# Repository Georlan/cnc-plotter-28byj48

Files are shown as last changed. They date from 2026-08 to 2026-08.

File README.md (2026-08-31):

# CNC Plotter 28BYJ-48 — baixo custo, impressa em 3D

Plotter cartesiana para papel A5, modelada parametricamente em OpenSCAD e
otimizada para fabricação na Bambu Lab A1.

Comece pelo [`GUIA_VISUAL_MONTAGEM.md`](GUIA_VISUAL_MONTAGEM.md). Para os
critérios detalhados dos cupons, lista de fixadores e diagnóstico, consulte
[`GUIA_TESTES_E_MONTAGEM.md`](GUIA_TESTES_E_MONTAGEM.md).

## Arquitetura atual

- Um único eixo X apoiado em **dois trilhos paralelos**.
- Trilho X dianteiro motriz: uma cremalheira, um pinhão e um 28BYJ-48.
- Trilho X traseiro passivo: sem cremalheira e sem segundo motor.
- Sapata PETG flutuante no apoio traseiro: `±0,60 mm` em Y para não travar por
  pequeno erro de paralelismo.
- Viga Y tubular de `30 x 24 mm`, parede de `1,8 mm`, diafragmas a cada
  `40 mm` e apoio nas duas extremidades.
- Papel parado; apenas pórtico, carrinho Y e caneta se movem.
- Z com mola metálica: o plástico guia a caneta, mas não define sozinho a
  pressão no papel.

O curso conservador é **148 x 180 mm** dentro de uma folha A5. A máquina segura
a folha inteira, mas mantém margem de 15 mm nas extremidades longas.

## Arquivos imprimíveis

| Arquivo | Conteúdo | Material |
|---|---|---|
| `01_Base_Trilho_X.scad` | trilho dianteiro com cremalheira | PLA |
| `01B_Trilho_X_Passivo.scad` | trilho traseiro sem cremalheira | PLA |
| `02_Carrinho_X.scad` | carrinho motriz + sela traseira | PLA |
| `02B_Sapata_X_Passiva_PETG.scad` | sapata flutuante | PETG |
| `03_Trilho_Y.scad` | viga-caixão Y com guia e rack | PLA |
| `04_Carrinho_Y.scad` | carrinho Y e suportes dos motores Y/Z | PLA |
| `05_Modulo_Z_Caneta.scad` | êmbolo Z + colar + mandril e buchas | PETG recomendado |
| `06_Pinhoes.scad` | três pinhões D de 10 dentes | PETG recomendado |
| `07_Batentes.scad` | quatro batentes X + dois Y, por pressão | PETG |
| `08_Clips_Fixacao_Papel.scad` | quatro clips de papel | PLA ou PETG |
| `91_Teste_Engrenamento_FDM.scad` | cupom rack + pinhão | material dos pinhões |
| `99B_Teste_Portaferramenta_FDM.scad` | cupom do mandril e buchas | PETG recomendado |
| `99D_Teste_Fixacao_Motor_28BYJ48.scad` | cupom da flange/ressalto do motor | PLA |

`02_Carrinho_X.scad` e `02B_Sapata_X_Passiva_PETG.scad` foram separados para
não exigir PLA e PETG na mesma placa.

### 3MF para abrir no Bambu Studio

Para imprimir pela Bambu Lab A1, prefira os arquivos da pasta
[`bambu_project_3mf/`](bambu_project_3mf/). Eles são exportados novamente pelo
**Bambu Studio oficial** e incluem a estrutura de projeto do Bambu, em vez de
serem apenas contêineres de malha 3MF produzidos pelo OpenSCAD.

O gerador está fixado em:

- Bambu Studio `2.8.2.61`;
- impressora `Bambu Lab A1 0.4 nozzle`;
- processo-base `0.16mm Optimal @BBL A1`;
- `Generic PLA @BBL A1` para `01`, `01B`, `02`, `03`, `04` e `08`;
- `Generic PETG @BBL A1` para `02B`, `05`, `06` e `07`.

Cada projeto é verificado como ZIP/3MF, precisa conter
`Metadata/project_settings.config` e `Metadata/model_settings.config`, e é
reaberto pelo Bambu Studio CLI antes de ser publicado pelo CI.

A pasta [`bambulab_3mf/`](bambulab_3mf/) continua existindo como saída
**geométrica** do OpenSCAD. Ela é útil para intercâmbio e inspeção, mas o Bambu
Studio pode tratá-la como 3MF genérico/importado e pedir confirmação de
configuração. Para o fluxo normal de impressão, use `bambu_project_3mf/`.

Os projetos Bambu usam um perfil-base válido; os ajustes mecânicos específicos
de brim, paredes e preenchimento continuam descritos na seção **Fatiamento
econômico na Bambu Lab A1** abaixo. Antes de enviar à impressora, confira na
placa o material selecionado e mantenha suporte desativado nas regiões de guia.

Para regenerar os dois conjuntos:

```bash
./build_3mf.sh
./build_bambu_project_3mf.sh
```

## Parâmetros principais

- Trilhos X: `220 x 26 mm`; distância entre centros: `240 mm`.
- Viga Y: `240 x 30 x 24 mm`.
- Guia XY: rabo de andorinha, folga inicial `0,22 mm` por lado.
- Guia Z: folga inicial `0,15 mm` por lado e 22 mm de comprimento guiado.
- Cremalheira: passo circular `4,0 mm`.
- Pinhão: 10 dentes, perfil involuta *stub*, ângulo de pressão de 30°.
- A raiz dos dentes tem `0,20 mm` de sobreposição no cubo para manter a peça
  manifold e evitar o falso efeito de transparência no preview OpenCSG.
- O módulo do pinhão força `render(convexity=10)`, necessário para o preview F5
  do OpenSCAD 2021 mostrar dentes sólidos em vez das faces vazadas do OpenCSG.
- Relação cinemática correta: **9° de pinhão por mm linear**; 4 mm correspondem
  a 36°, não a uma volta completa.

Antes das peças longas, imprima `99_Teste_Tolerancias.scad`,
`91_Teste_Engrenamento_FDM.scad` e `99D_Teste_Fixacao_Motor_28BYJ48.scad`.
Use a menor folga que deslize sem força após retirar rebarbas e valide o motor
real no cupom antes de gastar material com os carrinhos completos.

## Interface dos motores 28BYJ-48

A montagem dos três motores usa o **centro do eixo como datum**. O ressalto
frontal nominal de 9 mm entra num alojamento coaxial e localiza o motor em
relação ao pinhão. Os parafusos das orelhas servem apenas para prender o motor.

O desenho dimensional nominal do 28BYJ-48 possui `35 mm` entre os furos e uma
linha de furos deslocada aproximadamente `8 mm` em relação ao centro do eixo.
Como há variantes comerciais, os suportes usam dois rasgos M3 com `±2 mm` de
ajuste por orelha, cobrindo aproximadamente `31–39 mm` entre centros sem mover
o eixo. O modelo visual, os carrinhos X/Y/Z e os parafusos da montagem completa
usam a mesma interface canônica definida em `00_Parametros.scad`.

O motor Z é girado 180° ao redor do próprio eixo para que suas orelhas fiquem
abaixo do eixo e ancoradas na torre do carrinho Y. Isso não altera a posição do
pinhão nem a relação rack/pinhão.

## Porta-ferramenta universal

O guia Z continua usando uma haste rígida de `10 mm`, mas a ferramenta agora
fica num mandril externo de `24 mm` de altura. Isso permite trocar caneta por
pincel sem enfraquecer o êmbolo, alterar a mola ou reposicionar o motor Z.

- buchas incluídas para cabos redondos nominais de `7,5`, `10,0` e `12,5 mm`;
- cabos de aproximadamente `14–15 mm` podem ser presos sem bucha;
- use a menor bucha na qual o cabo entre sem força e aperte o M3 só até eliminar
  o giro; não comprima a madeira nem a virola metálica do pincel;
- prenda o cabo redondo acima da virola. Pincéis com cabo cônico devem ser
  posicionados numa região quase cilíndrica.

Imprima primeiro `99B_Teste_Portaferramenta_FDM.scad`: ele contém o mesmo
mandril da peça final, mas sem a longa haste, e evita gastar material caso seja
necessário recalibrar a folga para sua impressora.

## Altura e pressão da ferramenta

- Curso total do motor Z: `8 mm`.
- Compressão nominal no contato: `2 mm`.
- Elevação livre real: `6 mm`.
- Ponta baixa: `Z = 0,30 mm`, na superfície modelada do papel.
- Ponta alta: `Z = 6,30 mm`.
- Mola-alvo: `0,20 N/mm`, pré-carga de `1 mm`, curso complacente de `3 mm`.
- Força nominal modelada: aproximadamente `0,60 N`.
- Força no fim do curso complacente: aproximadamente `0,80 N`.

Uma mola entre `0,15 e 0,25 N/mm` é aceitável. Ajuste primeiro a altura do
colar com a máquina desligada; não use o motor para esmagar a ponta na mesa.

## Massa e rigidez

Volumes medidos nos STLs renderizados:

- peças móveis impressas: aproximadamente **154 g**;
- três motores, usando 35 g por motor como referência: aproximadamente 105 g;
- caneta, mola e fixadores móveis: aproximadamente 15–25 g;
- conjunto móvel estimado: **274–284 g**.

O valor dos motores varia por fabricante. A estimativa não substitui a pesagem.

Para a viga 30 x 24 x 1,8 mm, um cálculo simplificado de viga biapoiada com
1,3 N no centro e módulo de PLA de 1,8 GPa resulta em cerca de `0,013 mm` de
deflexão elástica. Isso não é FEA: juntas, empenamento e montagem fora de
esquadro dominarão o erro real.

## Fatiamento econômico na Bambu Lab A1

### Trilhos e viga em PLA

- camada: `0,24 mm`;
- gerador de paredes: Arachne;
- 3 paredes;
- 4 camadas de topo/fundo;
- 10% Gyroid nos blocos locais;
- brim de 5–8 mm nos trilhos de 220 mm e 5 mm na viga de 240 mm;
- suporte desativado.

### Carrinhos em PLA

- camada: `0,20 ou 0,24 mm`;
- 4 paredes;
- 15% Gyroid;
- suporte desativado.

### Sapata, Z e pinhões em PETG

- camada: `0,20 mm`;
- 4 paredes;
- pinhões: 100% de preenchimento;
- sapata/Z: 20–30%;
- seque o PETG antes de imprimir as superfícies de guia.

Os canais inferiores têm 0,25 mm de profundidade e pontes de no máximo 10 mm.
Não ative suporte dentro deles.

## Parafusos mínimos

- 8x M4 para os dois trilhos (quatro por trilho);
- 6x M3 para os três motores (dois por motor);
- 2x M3 para as extremidades da viga;
- 1x M3x8 para reter a sapata sem apertar a sela;
- 1x M3 para o colar da haste;
- 1x M3 com porca para o mandril da caneta ou do pincel.

Total estrutural: **19 parafusos**. Batentes são de pressão e os clips de papel
podem usar fita dupla-face.

## Montagem sem perder o esquadro

1. Fixe totalmente apenas o trilho dianteiro.
2. Deixe os quatro parafusos do trilho traseiro levemente soltos.
3. Monte os dois carrinhos e a viga, sem forçar a sapata passiva.
4. Desloque o pórtico manualmente por todo o X.
5. Aperte o trilho traseiro aos poucos, alternando posições do pórtico.
6. Aperte o M3 da sapata contra o ressalto; a sela deve continuar movendo
   aproximadamente `±0,60 mm`.
7. Só então monte motores e ajuste o engrenamento.

## Validação

Com o OpenSCAD CLI instalado:

```bash
python3 validate_geometry.py
```

Testes:

- `91_Teste_Engrenamento_FDM.scad`: cupom físico barato do perfil real;
- `92_Teste_Estrutural.scad`: dimensões, esbeltez e área A5;
- `93_Teste_Plano_Caneta.scad`: altura, elevação, força e guia Z;
- `94_Teste_Engrenamento_Dinamico.scad`: 17 amostras em um passo completo;
- `95_Teste_Montagem_Completa.scad`: interfaces e colisões estruturais;
- `96_Validacao_Curso.scad`: centro e quatro extremos para inspeção visual;
- `97_Diagnostico_Motores.scad`: corpo, flange, ressalto e eixo dos motores;
- `98_Teste_Interferencias.scad`: bolsos de pinhão e curso Z;
- `99_Teste_Tolerancias.scad`: cupom físico de folgas;
- `99_Teste_Folga_Pinhao_FDM.scad`: folgas radial e axial do bolso;
- `99B_Teste_Portaferramenta_FDM.scad`: mandril e três buchas redutoras;
- `99D_Teste_Fixacao_Motor_28BYJ48.scad`: ressalto, eixo e rasgos das orelhas.

Os testes 92–95 e 97–98 devem exportar somente seu cubo marcador de 1 mm.
Geometria adicional indica colisão.

Para gerar somente os STLs imprimíveis:

```bash
./build_stl.sh
```

## Limite elétrico

Não alimente um 28BYJ-48 de 5 V diretamente com 12 V. Esta revisão mecânica não
depende dessa modificação. Use aceleração moderada no firmware e valide perda
de passos com quadrados e círculos antes do trabalho final.

## Licença

Hardware aberto para uso pessoal e educacional.

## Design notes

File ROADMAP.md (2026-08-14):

# Roadmap — CNC Plotter 28BYJ-48

Este roadmap acompanha o estado real do projeto. As medidas continuam em
`00_Parametros.scad`; resultados físicos podem alterar folgas sem invalidar a
sequência abaixo.

## Estado atual

- [x] Estrutura paramétrica completa em OpenSCAD.
- [x] Trilhos X duplos, viga Y apoiada e módulo Z redesenhados.
- [x] Motores e pinhões posicionados nos três eixos.
- [x] Folgas de segurança e porta-ferramenta para caneta/pincel adicionados.
- [x] Testes de impressão e guias de montagem preparados.
- [x] Simulação 3D interativa em `GUIA_3D_INTERATIVO.html`.
- [ ] Validar as tolerâncias na impressora real.

## Fase 1 — Cupons antes das peças grandes

- [ ] Imprimir `91_Teste_Engrenamento_FDM.scad` e escolher o engrenamento que
  gira continuamente, sem salto e sem forçar o eixo.
- [ ] Imprimir `99_Teste_Folga_Pinhao_FDM.scad` e registrar a melhor folga.
- [ ] Imprimir `99_Teste_Tolerancias.scad` e registrar as folgas que deslizam
  sem jogo excessivo.
- [ ] Imprimir `99B_Teste_Portaferramenta_FDM.scad` com o material final e
  testar caneta e pincel.
- [ ] Atualizar somente os parâmetros correspondentes em `00_Parametros.scad`.

**Portão de avanço:** todos os cupons devem passar antes de imprimir trilhos,
viga e carrinhos completos.

## Fase 2 — Impressão e inspeção

- [ ] Gerar os STL com `build_stl.sh` após calibrar os cupons.
- [ ] Imprimir pinhões e peças de precisão primeiro; depois as peças longas.
- [ ] Remover rebarbas sem desgastar dentes ou superfícies de referência.
- [ ] Conferir empenamento, furos, encaixes, rachaduras e camadas.
- [ ] Separar parafusos, porcas, mola, motores, drivers e fonte.

## Fase 3 — Montagem mecânica sem energia

- [ ] Fixar o trilho X motriz e deixar o trilho X passivo levemente solto.
- [ ] Inserir os dois carrinhos X e montar sapata/sela passiva.
- [ ] Assentar a viga Y nas chavetas e usá-la para alinhar os trilhos X.
- [ ] Percorrer todo o curso X e apertar o trilho passivo gradualmente.
- [ ] Inserir o carrinho Y antes dos batentes.
- [ ] Montar êmbolo, mola, colar e porta-ferramenta do eixo Z.
- [ ] Instalar motores e aproximar os pinhões sem pré-carga radial.

**Portão de avanço:** X, Y e Z devem mover manualmente em todo o curso, sem
pontos duros, colisões, salto de dentes ou flexão visível dos eixos.

## Fase 4 — Elétrica e segurança

- [ ] Alimentar os três ULN2003 com fonte externa regulada de 5 V e margem de
  corrente; não alimentar todos os motores pelo pino 5 V do Arduino.
- [ ] Unir o GND da fonte ao GND do Arduino.
- [ ] Ligar um motor por vez e conferir temperatura, ruído e giro.
- [ ] Organizar cabos com folga para todo o curso e longe das engrenagens.
- [ ] Manter um desligamento rápido disponível nos primeiros testes.

| Eixo | ULN2003 no Arduino Uno |
|---|---|
| X | IN1–IN4 em D2–D5 |
| Y | IN1–IN4 em D6–D9 |
| Z | IN1–IN4 em D10–D13 |

## Fase 5 — Firmware e calibração

- [x] Firmware `CNC_Plotter_28BYJ48.ino` criado para três 28BYJ-48.
- [ ] Gravar o firmware e validar a serial em 115200 baud.
- [ ] Testar um eixo por vez em baixa velocidade.
- [ ] Mandar 10 mm, medir e recalcular `STEPS_PER_MM`; repetir com 50 mm.
- [ ] Ajustar velocidade e aceleração até eliminar perda de passos.
- [ ] Confirmar que Z não esmaga o pincel contra o papel.

## Fase 6 — Movimento e desenho

- [ ] Rodar o teste de interferências nos extremos do curso.
- [ ] Desenhar linhas, quadrado e diagonais; medir esquadro e repetibilidade.
- [ ] Executar `G-code-to-write-a-spiral.ngc` para movimento contínuo X/Y.
- [ ] Executar `G-code-to-write-ABC+Hatched.ngc` para validar X/Y/Z.
- [ ] Repetir o desenho três vezes e comparar retorno, pressão e passos perdidos.
- [ ] Registrar material, camada, folgas, passos/mm, velocidade e resultado.

## Fase 7 — Melhorias após a primeira máquina funcional

- [ ] Fins de curso e homing automático.
- [ ] Fixação definitiva do papel e superfície substituível.
- [ ] Alívio de tração e guia para cabos.
- [ ] Avaliar motores mais fortes somente se os testes comprovarem falta de
  torque; primeiro eliminar atrito, desalinhamento e pré-carga.

## Documentos de apoio

- `GUIA_3D_INTERATIVO.html` — montagem e movimento em 3D.
- `GUIA_VISUAL_MONTAGEM.md` — referência visual rápida.
- `GUIA_TESTES_E_MONTAGEM.md` — critérios e lista de fixadores.
- `CNC_Plotter_Animated_Simulation.scad` — simulação paramétrica no OpenSCAD.

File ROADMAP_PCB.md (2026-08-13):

# ⚡ ROADMAP AVANÇADO: Fabricação de Placas de Circuito Impresso (PCB) via Plotter CNC + Percloreto

Este roadmap foi otimizado para transformar a sua Mini CNC Plotter em uma estação dedicada à fabricação de **Placas de Circuito Impresso (PCB)** de alta precisão.

---

## 🚀 FASE 1: Hardware & Estabilidade Elétrica (Urgente)
- [ ] **Alimentação Externa 5V (2A)**:
  - Não alimentar os 3 drivers ULN2003 pela USB do Arduino.
  - Conectar fonte de 5V 2A na protoboard + GND comum no Arduino.
- [ ] **Ajuste Mecânico de Precisão (Eliminar Folgas / Backlash)**:
  - A corrosão em percloreto exige precisão de $0.1\text{ mm}$.
  - Verificar se a engrenagem do pinhão está bem presa no eixo do motor 28BYJ-48 sem patinar.
  - Adicionar molas ou pressão suave no eixo Z para a caneta não variar a força no cobre.

---

## 🖥️ FASE 2: Frontend Web Customizada (`CNC PCB Commander`)
- [x] **Substituição do UGS por Interface Nativa Otimizada**:
  - Criado servidor local `cnc_web_server.py` e frontend moderna em `http://localhost:8080`.
- [x] **Recursos Específicos para PCB na Web App**:
  - Visualizador 2D em tempo real das trilhas de cobre (G0 em vermelho, G1 em verde néon).
  - Controle de Jogging com precisão de $0.1\text{ mm}$, $1.0\text{ mm}$ e $5.0\text{ mm}$.
  - Botão rápido de teste de profundidade da caneta (`Z5` subir / `Z-1` baixar).
  - Transmissor G-code integrado via WebSockets (sem necessidade de Java ou UGS).

---

## 🎨 FASE 3: Fluxo de G-Code de PCB (Gerber / SVG $\rightarrow$ G-Code)
- [ ] **Desenho da Placa no CAD (KiCad / EasyEDA)**:
  - Desenhar as trilhas com largura mínima de $0.5\text{ mm}$ ($20\text{ mil}$) e pads aumentados para facilitar a furação.
  - Exportar o layer de trilhas (*Bottom Copper*) em SVG ou Gerber.
- [ ] **Compensação de Espessura da Caneta (Inkscape)**:
  - Importar o SVG no Inkscape.
  - Converter trilhas em contornos com traço de $0.4\text{ mm}$ (diâmetro exato da ponta da caneta permanente).
  - Gerar o G-code utilizando o plugin *Inkscape Gcodetools*.

---

## 🧪 FASE 4: Processo de Desenho e Corrosão em Percloreto de Ferro ($\text{FeCl}_3$)
- [ ] **1. Preparação da Placa de Fenolite / Cobre**:
  - Lixar suavemente a placa de cobre com palha de aço bem fina (Bombril) até o cobre ficar brilhante e 100% sem oxidação.
  - Limpar com álcool isopropílico para remover qualquer oleosidade de dedos (a gordura impede a aderência da tinta e do ácido).
- [ ] **2. Caneta Recomendada**:
  - Utilizar canetas permanentes à base de solvente e resistentes a ácido:
    - *Staedtler Lumocolor Permanent (Ponta S 0.4mm ou F 0.6mm)*
    - *Pilot CD/DVD Marker*
- [ ] **3. Desenho Automático com Passe Duplo**:
  - Fixar a placa na mesa da CNC com fita dupla face para não mover.
  - Zerar a caneta no canto inferior esquerdo da placa (`X0, Y0, Z0`).
  - Executar o desenho via **CNC PCB Commander** (`http://localhost:8080`).
  - Habilitar o **Passe Duplo de Tinta** no painel da Web App para garantir camada espessa que impede o percloreto de corroer microfuros na tinta.
- [ ] **4. Banho de Percloreto de Ferro**:
  - Diluir o percloreto em recipiente plástico (nunca metálico!).
  - Dica de Ouro: Aqueça a água da solução até $\sim 40^\circ\text{C}$ e agite suavemente a placa durante a corrosão. O processo levará apenas de 8 a 12 minutos.
- [ ] **5. Limpeza e Furação**:
  - Remover a tinta preta com álcool ou acetona.
  - Furar os ilhós dos componentes com mini furadeira / retífica e broca de $0.8\text{ mm}$ a $1.0\text{ mm}$.

---

## 🎯 FASE 5: Automações Futuras na CNC
- [ ] Implementação de Auto-Leveling (Mapeamento de desnível da placa de cobre via pino sensor no Arduino).
- [ ] Adaptação de spindle / micro-retífica para furação automática de PCBs.

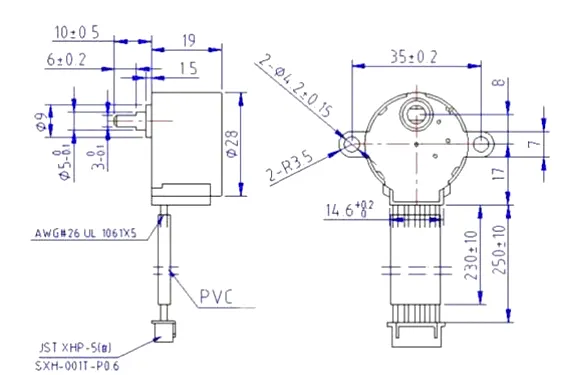
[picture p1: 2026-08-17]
28BYJ-48-dimensions.webp

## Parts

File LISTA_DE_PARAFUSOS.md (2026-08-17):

# 🔩 Lista de Parafusos e Fixadores — CNC Plotter 28BYJ-48

Esta é a lista completa de todos os parafusos, porcas e elementos de fixação necessários para a montagem completa da CNC.

---

## 📋 1. Tabela Detalhada de Aplicação

| Item | Qtd | Especificação | Onde é usado | Instrução de Aperto |
|:---:|:---:|:---|:---|:---|
| **1** | **8x** | **M4** *(12mm a 20mm, dependendo da base)* | Fixação dos dois Trilhos X na base de MDF | Firme, sem deformar o piso plástico do trilho |
| **2** | **6x** | **M3 x 8mm** + **6x Porcas M3** | Fixação dos 3 motores 28BYJ-48 (2 por motor: X, Y, Z) | Aperto suave nas orelhas metálicas do motor |
| **3** | **2x** | **M3 x 10mm** | Fixação das 2 pontas da Viga Y nos carrinhos X | Rosca direta no piloto plástico; sem espanar |
| **4** | **1x** | **M3 x 8mm** | Parafuso limitador da sela/sapata passiva traseira | Encostar no ressalto sem travar a flutuação lateral |
| **5** | **1x** | **M3 x 12mm** + **1x Porca M3** | Aperto do colar limitador da haste Z | Firme para não escorregar durante o desenho |
| **6** | **1x** | **M3 x 14mm** (ou 16mm) + **1x Porca M3** | Aperto do mandril universal (caneta/pincel) | Apertar até travar o giro, sem esmagar o cabo |

---

## 📦 2. Resumo Consolidado para Compra

### Parafusos (Total: 19 unidades)
- [ ] **8x** Parafusos **M4** (Comprimento conforme sua base: 12mm a 20mm)
- [ ] **7x** Parafusos **M3 x 8mm** (Cabeça Cilíndrica Allen ou Philips)
- [ ] **2x** Parafusos **M3 x 10mm**
- [ ] **1x** Parafuso **M3 x 12mm**
- [ ] **1x** Parafuso **M3 x 14mm** (ou 16mm)

### Porcas e Arruelas
- [ ] **8x** Porcas sextavadas **M3**
- [ ] **8x** Arruelas lisas **M4** *(Recomendado para não marcar o plástico da base X)*
- [ ] **6x** Arruelas lisas **M3** *(Recomendado para as abas dos motores)*

### Molas e Complementos
- [ ] **1x** **Mola de compressão metálica** *(Diâmetro externo: 6 a 8 mm, Comprimento livre: 15 a 25 mm, Rigidez leve/média — pode usar mola de caneta retrátil)*
- [ ] **4x** Fixadores opcionais para os clips de papel *(ou fita dupla face)*

---

## 💡 Dicas de Montagem:
1. **Nunca aperte excessivamente no plástico:** Os furos pilotos impressos em 3D aceitam rosca do próprio parafuso M3, mas apertar com força excessiva pode espanar a rosca interna.
2. **Alojamentos de Porcas Hexagonais:** No mandril da caneta e nos suportes dos motores, os encaixes das porcas M3 foram desenhados para encaixe sob leve pressão. Se a porca entrar justa, puxe-a para o lugar rosqueando o parafuso pelo lado oposto.

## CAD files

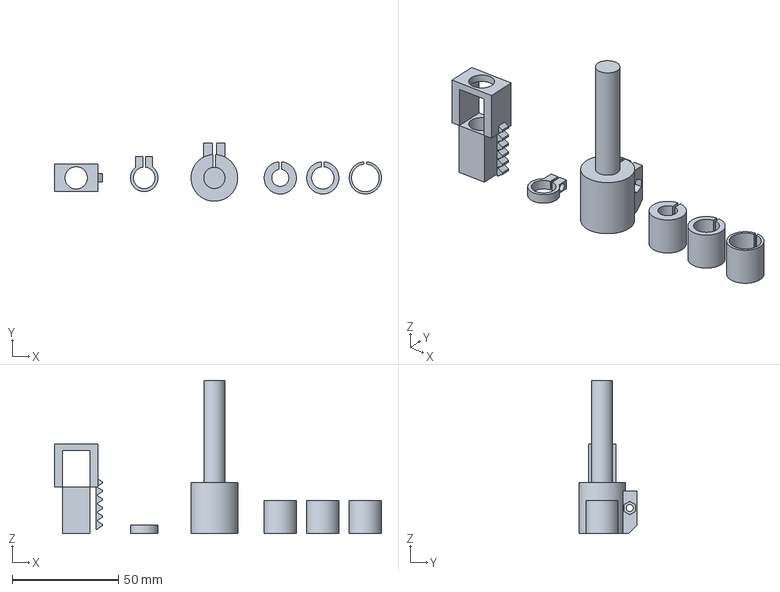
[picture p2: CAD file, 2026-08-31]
bambu_project_3mf/05_Modulo_Z_Caneta.3mf
153.8 x 27.5 x 72.0 mm

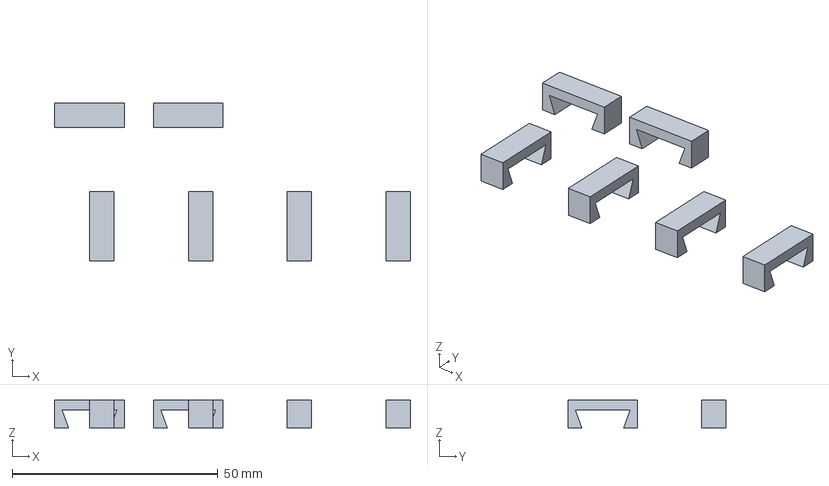
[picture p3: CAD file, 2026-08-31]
bambulab_3mf/07_Batentes.3mf
86.5 x 38.5 x 6.70 mm

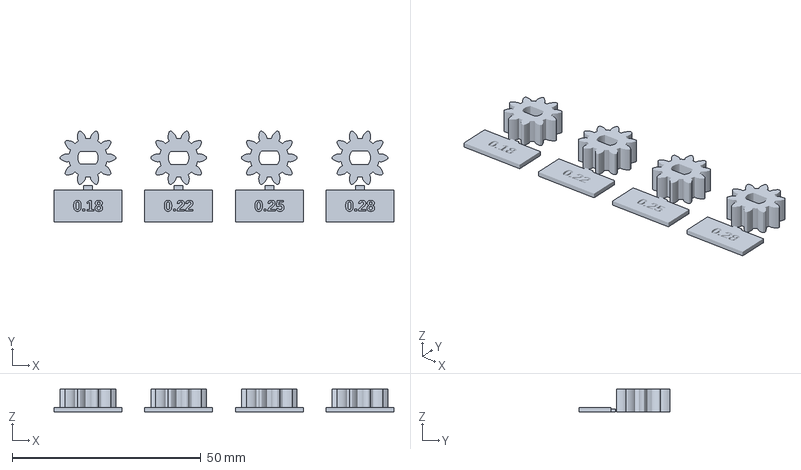
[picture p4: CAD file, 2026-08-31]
bambulab_3mf/testes/99_Teste_Eixo_D.3mf
90.0 x 24.1 x 6.00 mm

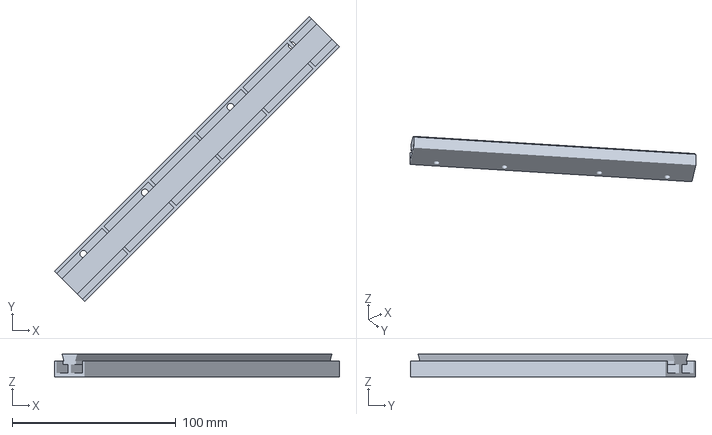
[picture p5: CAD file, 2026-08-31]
bambu_project_3mf/01B_Trilho_X_Passivo.3mf
173.9 x 173.9 x 14.0 mm

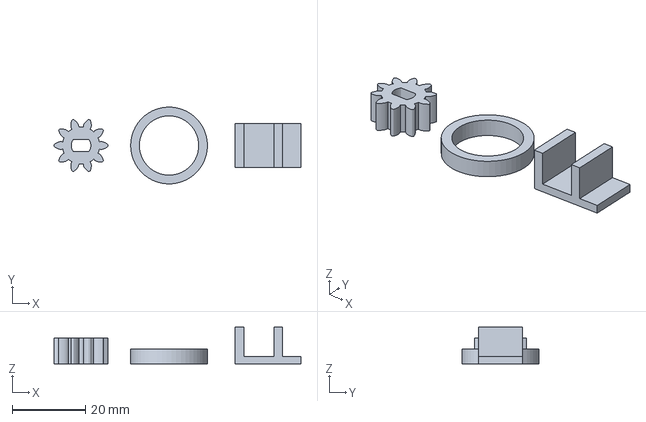
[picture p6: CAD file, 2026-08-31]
bambulab_3mf/testes/99_Teste_Folga_Pinhao_FDM.3mf
67.4 x 20.9 x 10.0 mm

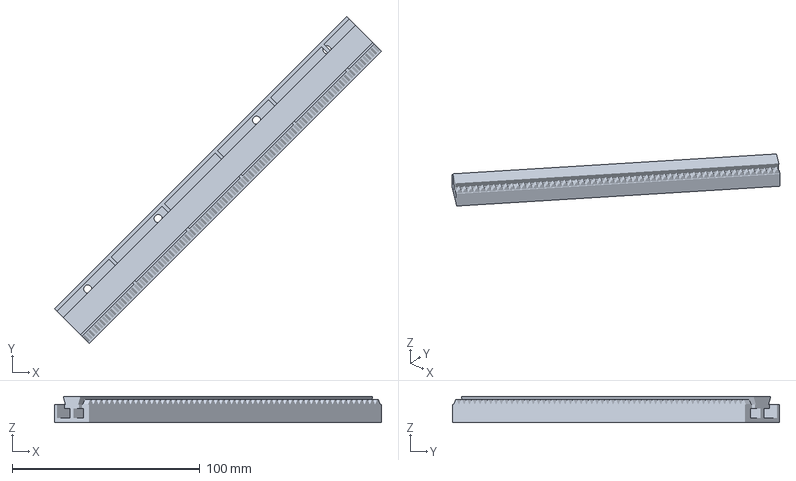
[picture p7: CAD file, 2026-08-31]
bambu_project_3mf/01_Base_Trilho_X.3mf
173.9 x 173.9 x 14.0 mm

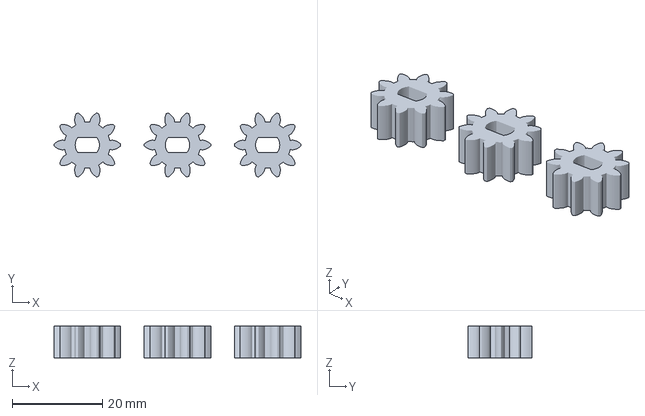
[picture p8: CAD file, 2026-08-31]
bambulab_3mf/06_Pinhoes.3mf
54.8 x 14.2 x 7.00 mm

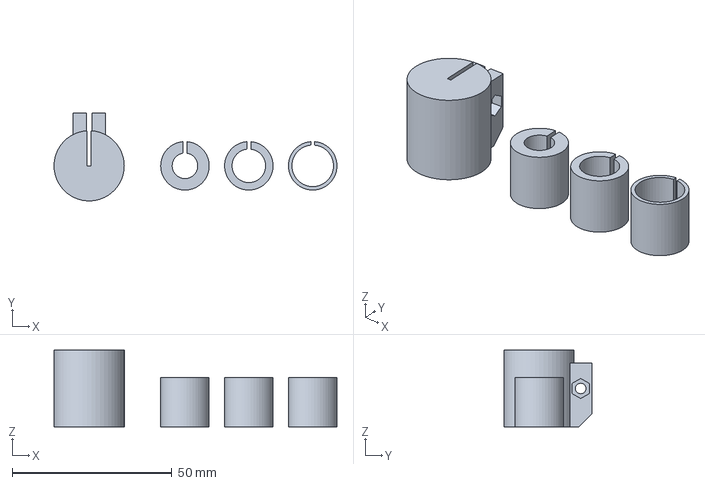
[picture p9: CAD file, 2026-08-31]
bambulab_3mf/testes/99B_Teste_Portaferramenta_FDM.3mf
88.6 x 27.5 x 24.0 mm

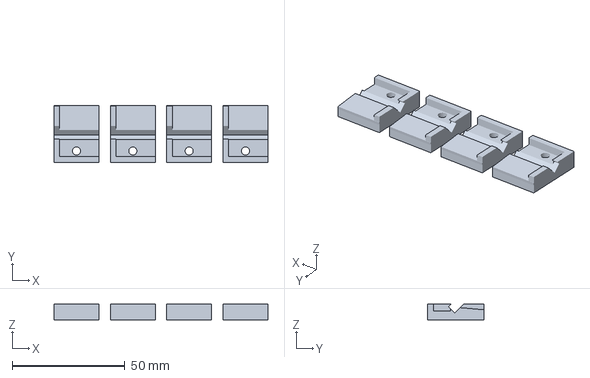
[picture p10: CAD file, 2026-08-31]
bambulab_3mf/08_Clips_Fixacao_Papel.3mf
95.0 x 25.1 x 7.00 mm

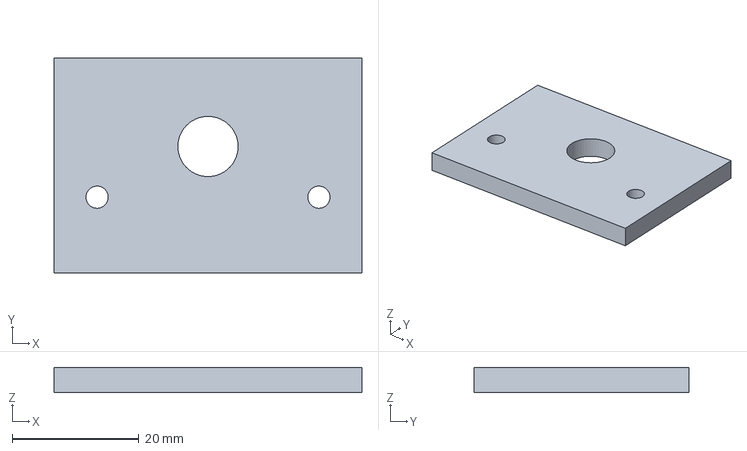
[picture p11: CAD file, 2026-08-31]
bambulab_3mf/testes/99D_Teste_Fixacao_Motor_28BYJ48.3mf
48.6 x 34.0 x 4.00 mm

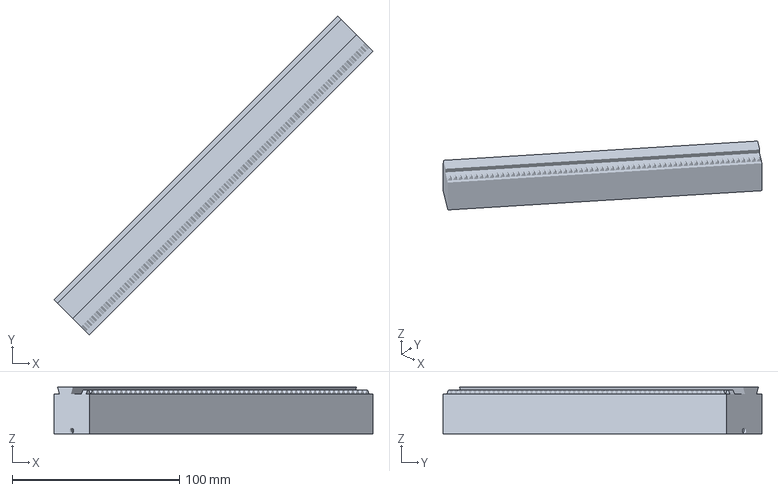
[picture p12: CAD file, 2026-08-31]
bambu_project_3mf/03_Trilho_Y.3mf
190.9 x 190.9 x 28.0 mm

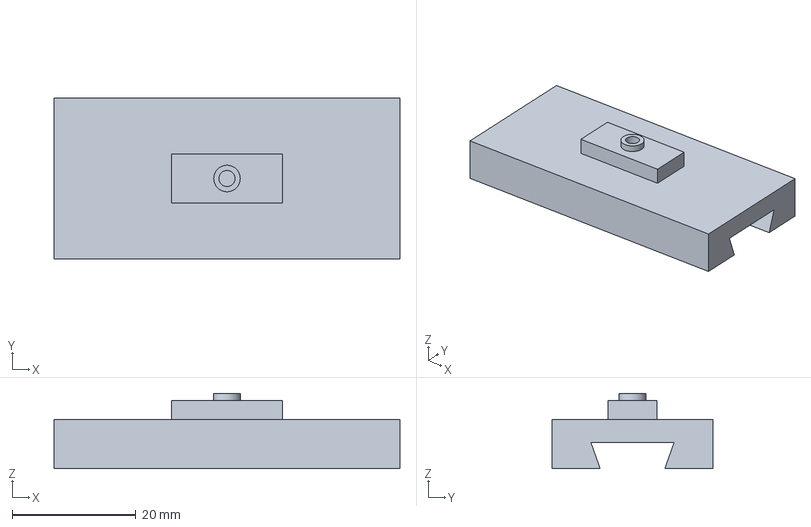
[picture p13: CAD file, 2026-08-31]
bambulab_3mf/02B_Sapata_X_Passiva_PETG.3mf
56.0 x 26.0 x 12.2 mm

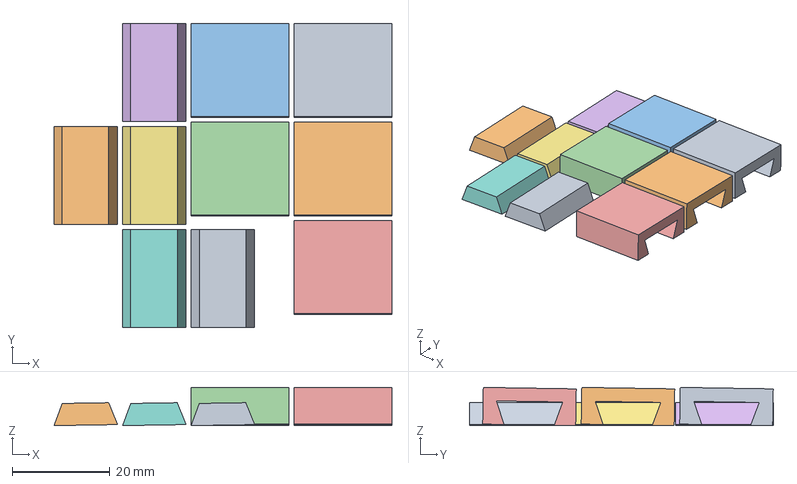
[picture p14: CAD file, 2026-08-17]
bambulab_3mf/testes/99_Teste_Tolerancias.3mf
69.0 x 62.0 x 7.80 mm
99_Teste_Tolerancias.stl_1
99_Teste_Tolerancias.stl_2
99_Teste_Tolerancias.stl_3
99_Teste_Tolerancias.stl_4
99_Teste_Tolerancias.stl_5
99_Teste_Tolerancias.stl_6
99_Teste_Tolerancias.stl_7
99_Teste_Tolerancias.stl_8
99_Teste_Tolerancias.stl_9
99_Teste_Tolerancias.stl_10

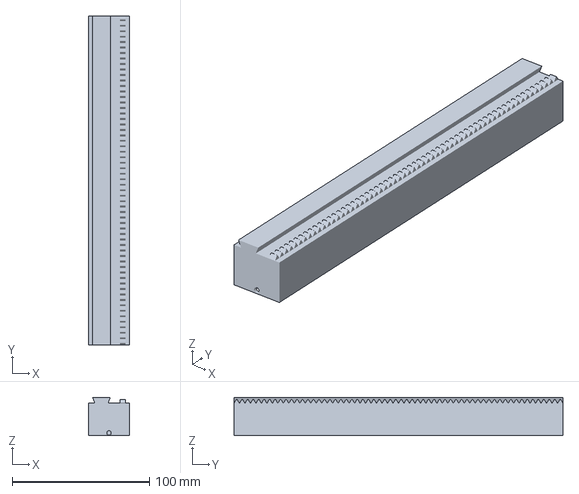
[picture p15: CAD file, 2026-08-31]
bambulab_3mf/03_Trilho_Y.3mf
30.0 x 240.0 x 28.0 mm

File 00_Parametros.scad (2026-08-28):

/*
  Parametros globais — portico apoiado em dois trilhos X.

  Sistema de coordenadas da montagem:
    X = largura do desenho / deslocamento do portico
    Y = comprimento do papel / deslocamento do carrinho da caneta
    Z = vertical; superficie da bancada em Z=0

  Materiais previstos:
    PLA  : trilhos, viga-caixao e carrinhos rigidos
    PETG : sapata passiva flutuante do segundo trilho
*/

$fn = 50;
EPS = 0.01;

// Folgas por lado. Confirmadas nos testes físicos FDM.
slide_clearance_xy = 0.22; // Validado no Teste 99 (Par #3)
slide_clearance_z  = 0.15;
passive_float      = 0.60; // +/-0,60 mm transversal; 1,20 mm total
pressfit_clearance = 0.15;
shaft_clearance    = 0.18; // Validado no Teste de Eixo D (#1)

wall_thin       = 1.80;
wall_structural = 2.40;
wall_screw      = 4.50;

// Motor 28BYJ-48.
//
// IMPORTANTE: o eixo e o datum mecanico. Os furos das orelhas NAO passam pela
// linha do eixo: o desenho dimensional nominal mostra 35 mm entre centros e
// aproximadamente 8 mm entre o eixo e a linha dos furos. Variantes comerciais
// podem usar outro espacamento; por isso a peca impressa usa rasgos de ajuste
// e o ressalto frontal de 9 mm localiza o motor coaxialmente ao pinhao.
motor_body_diameter  = 28.0;
motor_mount_spacing  = 35.0; // nominal de referencia; nao define o eixo
motor_mount_line_offset = 8.0; // magnitude; no frame local os furos ficam em Y=-8
motor_mount_slot_adjust = 2.0; // +/-2 mm por orelha -> cobre ~31 a 39 mm C-C
motor_mount_spacing_min = motor_mount_spacing - 2*motor_mount_slot_adjust;
motor_mount_spacing_max = motor_mount_spacing + 2*motor_mount_slot_adjust;
motor_mount_screw_clearance_r = 1.75; // rasgo Ø3,5 mm para parafuso M3
motor_mount_pad_r    = 4.80;
motor_mount_pad_depth = 3.20;

motor_shaft_diameter = 5.0;
motor_shaft_flat     = 3.0;
motor_shaft_flat_len = 6.0;
motor_shaft_length   = 8.5;
motor_body_r         = motor_body_diameter / 2;
motor_body_h         = 19.0;
motor_flange_dist    = motor_mount_spacing;
motor_flange_hole_r  = 2.1;  // furo real da orelha do motor, nao o rasgo impresso
motor_flange_outer_r = 3.5;
motor_flange_thickness = 1.0;
motor_boss_r         = 4.5;
motor_boss_h         = 1.5;
motor_shaft_r        = motor_shaft_diameter / 2;
motor_mount_clearance = 0.25;
motor_x_mount_standoff = 3.3;

// Estrutura fixa X. Os centros dos trilhos ficam em Y=0 e Y=x_rail_spacing.
x_rail_length     = 220.0;
x_rail_spacing    = 240.0;
base_w            = 26.0;
base_h            = 10.0;
floor_h           = 2.4;
x_rack_center_y   = 2.8; // lado externo; pinhao livre da guia central
x_carriage_length = 56.0;
x_carriage_h      = 12.0;
passive_shoe_h    = 8.0;
passive_saddle_h  = x_carriage_h - passive_shoe_h;
passive_boss_w    = 18.0;
passive_boss_d    = 8.0;
passive_boss_h    = 3.0;

// Viga Y: tubo fechado com diafragmas.
y_rail_length         = x_rail_spacing;
y_beam_w              = 30.0;
y_beam_h              = 24.0;
y_beam_wall           = 1.80;
y_beam_rib_pitch      = 40.0;
y_beam_rib_t          = 1.80;
y_dovetail_center_x   = -5.5;
y_rack_center_x       = 10.0;
beam_key_w            = 20.0;
beam_key_d            = 16.0;
beam_key_h            = 4.0;
beam_key_inset        = y_beam_wall;
beam_socket_clearance = 0.20;
beam_mount_hole_r     = 1.65; // M3

// Cremalheira e pinhao impressos
rack_pitch        = 4.0;
gear_teeth        = 10;
gear_pitch_radius = (gear_teeth * rack_pitch) / (2 * PI);
gear_module        = rack_pitch / PI;
gear_pressure_angle = 30.0;
gear_addendum      = 0.80 * gear_module;
gear_dedendum      = 1.00 * gear_module;
tooth_height       = gear_addendum + gear_dedendum;
rack_pitch_height  = gear_dedendum;
rack_tooth_base_hw = rack_pitch/4
                     + gear_dedendum*tan(gear_pressure_angle);
rack_tooth_tip_hw  = rack_pitch/4
                     - gear_addendum*tan(gear_pressure_angle);
gear_root_radius   = gear_pitch_radius - gear_dedendum;
gear_tip_radius    = gear_pitch_radius + gear_addendum;
gear_outer_radius  = gear_tip_radius;
gear_backlash      = 0.20;
gear_mesh_clearance = 0.15;
// Folga do bolso, sem alterar a distancia de engrenamento. Os valores incluem
// margem para pe de elefante, leve empenamento e excentricidade de impressao.
pinion_pocket_radial_clearance = 0.70;
pinion_pocket_axial_clearance  = 0.60;
// Sobrepoe a raiz de cada dente ao disco central. Sem esta intersecao real,
// o preview OpenCSG exibe faces coplanares como se o pinhao fosse transparente.
gear_tooth_root_overlap = 0.20;
rack_width         = 4.0;
pinion_thickness   = 7.0;
pinion_tooth_width_pitch = rack_pitch / 2 - gear_backlash;
pinion_phase_x     = 18.0;
pinion_phase_y     = 0.0;
pinion_phase_z     = 18.0;
pinion_phase_deg   = pinion_phase_x;

// Guia rabo de andorinha
dovetail_height       = 4.5;
dovetail_width_bottom = 9.5;
dovetail_width_top    = 13.0;

// Carrinho Y e Z
y_carriage_w      = 44.0;
y_carriage_length = 48.0;
y_carriage_h      = 14.0;
z_guide_total_h   = 22.0;
z_axis_center_x_local = 10.0;
z_axis_center_y_local = 10.0;

z_motor_travel       = 8.0;
pen_lift_clearance   = 6.0;
nominal_compression  = 2.0;
compliance_travel    = 3.0;
// O mecanismo Z guia uma haste padrao de 10 mm. A ferramenta real fica em um
// mandril externo com buchas, portanto caneta e pincel nao precisam ter 10 mm.
tool_carrier_stem_diameter = 10.0;
pen_diameter         = tool_carrier_stem_diameter; // compatibilidade
pen_clearance        = 0.25;
spring_inner_diameter = 10.8;
spring_outer_diameter = 13.0;
spring_length         = 14.0;
spring_rate_target    = 0.20;
spring_preload        = 1.0;

tool_holder_bore_diameter = 15.5;
tool_holder_outer_diameter = 22.0;
tool_holder_height    = 24.0;
tool_holder_grip_h    = 16.0;
tool_holder_slit      = 1.20;
tool_holder_top_gap   = 4.0;
tool_carrier_stem_length = 48.0;
tool_sleeve_outer_diameter = 15.2;
tool_sleeve_height    = 15.5;
tool_sleeve_clearance = 0.25;
tool_sleeve_sizes     = [7.5,10.0,12.5];

z_carriage_w      = 13.0;
z_carriage_d      = 13.0;
z_carriage_body_h = 22.0;
z_collar_od       = 13.0;
z_collar_h        = 4.0;
z_cage_w          = 20.4;
z_cage_d          = 13.0;
z_post_w          = 3.8;
z_cap_h           = 3.0;
z_cap_bottom      = z_carriage_body_h + z_collar_h
                    + spring_length - spring_preload;
z_rack_start      = 2.0;
z_rack_length     = z_motor_travel + 16.0;
z_rack_base_x     = z_cage_w/2 - 0.20;
z_mesh_clearance  = gear_mesh_clearance;
z_pinion_offset_x = z_rack_base_x + rack_pitch_height
                    + gear_pitch_radius + z_mesh_clearance;
z_motor_axis_x_local = z_axis_center_x_local + z_pinion_offset_x;
z_motor_axis_z_local = 20.5;

// Planos globais da montagem
paper_width       = 148.0;
paper_height      = 210.0;
paper_z           = 0.0;
paper_thickness   = 0.30;
paper_origin_x    = 36.0;
paper_origin_y    = 15.0;
y_beam_bottom_z   = base_h + x_carriage_h;
y_beam_top_z      = y_beam_bottom_z + y_beam_h;
z_plunger_down_z  = y_beam_top_z + 0.50;
pen_tip_uncompressed_z = paper_z + paper_thickness
                         - z_plunger_down_z - nominal_compression;

// Curso conservador: cobre 148 x 180 mm dentro de uma folha A5.
X_MIN = paper_origin_x;
X_MAX = paper_origin_x + paper_width;
Y_MIN = paper_origin_y + 15.0;
Y_MAX = paper_origin_y + paper_height - 15.0;
Z_DOWN = 0.0;
Z_UP   = z_motor_travel;

SHOW_DEBUG       = false;
SHOW_MOTORS      = true;
SHOW_WORK_AREA   = false;
EXPLODED_VIEW    = 0.0;

// Uma volta corresponde a gear_teeth*rack_pitch (40 mm para 10T x 4 mm).
function pinion_angle(linear_position, direction=-1,
                      phase=pinion_phase_deg) =
  phase + direction * linear_position * 360
          / (gear_teeth*rack_pitch);

// =============================================================================
// Interface canonica de montagem do 28BYJ-48
// =============================================================================
// Frame local do motor:
//   origem = centro do eixo na face de montagem
//   +Z     = direcao de saida do eixo
//   furos  = X=+/-spacing/2, Y=-motor_mount_line_offset
//
// X/Y usam as orelhas acima do eixo na maquina para manter material de apoio.
// Z gira 180 graus ao redor do eixo e usa as orelhas abaixo do eixo, evitando
// uma ponte desconectada acima da torre do carrinho Y.
module orient_motor_x() { rotate([-90,0,0]) children(); }
module orient_motor_y() { rotate([0,-90,0]) rotate([0,0,90]) children(); }
module orient_motor_z() { rotate([-90,0,0]) rotate([0,0,180]) children(); }

module motor_28byj48_mount_hole_instances() {
  for (sx=[-1,1])
    translate([sx*motor_mount_spacing/2,-motor_mount_line_offset,0])
      children();
}
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

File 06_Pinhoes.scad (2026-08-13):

/*
  =============================================================================
  06_Pinhoes.scad - Pinhoes involuta stub para os eixos X, Y e Z
  =============================================================================
  Correções:
    - Dentes involuta stub com angulo de pressao de 30 graus
    - Raizes com sobreposicao volumetrica no cubo, sem efeito transparente no F5
    - Diametro externo nominal = 2 x gear_tip_radius = 14.77 mm
    - D-shaft hole unificado com d_shaft_hole()
    - 3 pinhões separados (X, Y, Z) para impressão individual
  
  Resultado: 3 COMPONENTES INDEPENDENTES no STL (um por pinhao)
  
  Geometria:
    gear_teeth = 10
    rack_pitch = 4.0 mm
    pitch_radius ≈ 6.366 mm  (primitivo)
    root_radius  ≈ 5.093 mm  (raiz)
    tip_radius   ≈ 7.385 mm  (ponta do dente)
    outer_diameter ≈ 14.77 mm (nominal)
  =============================================================================
*/

include <00_Parametros.scad>;

// Renderização dos 3 pinhões dispostos lado a lado para impressão
// Pinhão X
color([1.0, 0.50, 0.08, 1.0])
  translate([0, 0, 0])
    pinion_gear(thickness=pinion_thickness);

// Pinhão Y
color([1.0, 0.50, 0.08, 1.0])
  translate([20, 0, 0])
    pinion_gear(thickness=pinion_thickness);

// Pinhão Z
color([1.0, 0.50, 0.08, 1.0])
  translate([40, 0, 0])
    pinion_gear(thickness=pinion_thickness);

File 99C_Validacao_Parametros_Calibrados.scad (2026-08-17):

/*
  Guarda de regressao dos parametros calibrados em 2026-08-17.
  Resultado correto: um cubo de 1 mm.
*/

include <00_Parametros.scad>;

TOL = 1e-6;

assert(abs(slide_clearance_xy - 0.22) < TOL,
       "slide_clearance_xy deve permanecer em 0.22 mm (Teste 99, par #3)");
assert(abs(slide_clearance_z - 0.15) < TOL,
       "slide_clearance_z deve permanecer em 0.15 mm");
assert(abs(passive_float - 0.60) < TOL,
       "passive_float deve permanecer em 0.60 mm");
assert(abs(pressfit_clearance - 0.15) < TOL,
       "pressfit_clearance deve permanecer em 0.15 mm");
assert(abs(shaft_clearance - 0.18) < TOL,
       "shaft_clearance deve permanecer em 0.18 mm (Teste Eixo Double-D #1)");

assert(abs(motor_body_diameter - 28.0) < TOL,
       "28BYJ-48: corpo deve ser Ø28.0 mm");
assert(abs(motor_mount_spacing - 35.0) < TOL,
       "28BYJ-48: espaçamento de montagem deve ser 35.0 mm");
assert(abs(motor_shaft_diameter - 5.0) < TOL,
       "28BYJ-48: eixo deve ser Ø5.0 mm");
assert(abs(motor_shaft_flat - 3.0) < TOL,
       "28BYJ-48: espessura entre faces Double-D deve ser 3.0 mm");
assert(abs(motor_shaft_flat_len - 6.0) < TOL,
       "28BYJ-48: comprimento das faces Double-D deve ser 6.0 mm");
assert(abs(motor_shaft_length - 8.5) < TOL,
       "28BYJ-48: comprimento livre do eixo deve ser 8.5 mm");
assert(abs(motor_flange_hole_r - 2.1) < TOL,
       "28BYJ-48: furos de flange devem ter raio 2.1 mm");
assert(abs(motor_boss_r - 4.5) < TOL,
       "28BYJ-48: boss deve ter raio 4.5 mm");

assert(motor_shaft_flat < motor_shaft_diameter,
       "Geometria Double-D inválida: largura entre faces deve ser menor que o diâmetro");

cube([1,1,1]);

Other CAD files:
bambulab_3mf/05_Modulo_Z_Caneta.3mf
bambu_project_3mf/07_Batentes.3mf
bambu_project_3mf/08_Clips_Fixacao_Papel.3mf
bambulab_3mf/testes/91_Teste_Engrenamento_FDM.3mf
00_MotorMount_Final.scad
01B_Trilho_X_Passivo.scad
01_Base_Trilho_X.scad
02B_Sapata_X_Passiva_PETG.scad
02_Carrinho_X.scad
03_Trilho_Y.scad
04_Carrinho_Y.scad
05_Modulo_Z_Caneta.scad
07_Batentes.scad
08_Clips_Fixacao_Papel.scad
90_Componentes_Referencia.scad
91_Teste_Engrenamento_FDM.scad
92_Teste_Estrutural.scad
93_Teste_Plano_Caneta.scad
94_Teste_Engrenamento_Dinamico.scad
95_Teste_Montagem_Completa.scad
96_Validacao_Curso.scad
97_Diagnostico_Motores.scad
98_Teste_Interferencias.scad
99B_Teste_Portaferramenta_FDM.scad
99D_Teste_Fixacao_Motor_28BYJ48.scad
99_Teste_Eixo_D.scad
99_Teste_Folga_Pinhao_FDM.scad
99_Teste_Tolerancias.scad
CNC_Plotter_Animated_Simulation.scad
CNC_Plotter_Full_Assembly.scad
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

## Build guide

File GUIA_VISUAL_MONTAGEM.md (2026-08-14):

# Guia visual de testes e montagem

## Simulação 3D interativa

Abra [`GUIA_3D_INTERATIVO.html`](GUIA_3D_INTERATIVO.html) em um navegador para
girar a máquina, aplicar zoom e acompanhar as peças entrando em sete etapas.
Use **Montar** para reproduzir a sequência automaticamente; na última etapa,
os três eixos e os pinhões são animados juntos.

> No GitHub, baixe o arquivo HTML e abra-o localmente. O visual abaixo continua
> útil como folha de referência rápida durante a bancada.

Infográfico completo de testes, peças, fixadores e montagem

## Como usar

1. Comece pelos quatro cupons da primeira faixa.
2. Só imprima as peças longas depois que os quatro estiverem aprovados.
3. Monte seguindo a sequência numerada; o trilho traseiro só recebe o aperto
   final depois que o pórtico estiver correndo livre.
4. Confira o mapa dos fixadores antes de apertar qualquer subconjunto.
5. Faça o controle manual mostrado no quadro verde antes de energizar.

As dimensões continuam centralizadas em `00_Parametros.scad`. O infográfico
mostra relações, posição e ordem de montagem, portanto continua válido após
uma recalibração de folgas.

Para critérios detalhados de aprovação, diagnóstico e registro dos resultados,
consulte [`GUIA_TESTES_E_MONTAGEM.md`](GUIA_TESTES_E_MONTAGEM.md).

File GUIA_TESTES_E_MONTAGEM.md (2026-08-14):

# Guia didático de testes e montagem

Este guia acompanha a CNC Plotter 28BYJ-48 desde os primeiros cupons até o
primeiro desenho. Ele foi escrito para continuar válido quando as medidas do
projeto forem recalibradas.

## 1. Regra principal: parâmetros, não medidas copiadas

As medidas vigentes estão em `00_Parametros.scad`. Não copie dimensões de uma
captura de tela, de um STL antigo ou deste guia. Quando um teste físico indicar
outra folga, altere primeiro o parâmetro correspondente e gere novamente as
peças afetadas.

Antes de cada rodada anote:

- impressora, bico, material e perfil de fatiamento;
- altura de camada, número de paredes e compensação de pé de elefante;
- nome do arquivo e data em que o STL foi gerado;
- resultado observado, sem corrigir a peça com lixa antes de medir;
- folga escolhida e qualquer ruído, ponto duro ou movimento lateral.

Remova apenas fios, rebarbas soltas e o pé de elefante evidente. Lixar uma guia
até ela caber esconde o valor que deveria ser corrigido no modelo.

## 2. Inventário

### 2.1 Peças impressas finais

| Arquivo | O que sai na placa | Onde fica |
|---|---|---|
| `01_Base_Trilho_X.scad` | 1 trilho X motriz | frente da máquina; rack voltado para fora e para cima |
| `01B_Trilho_X_Passivo.scad` | 1 trilho X passivo | atrás; paralelo ao trilho motriz |
| `02_Carrinho_X.scad` | 1 carrinho X motriz + 1 sela rígida | carrinho no trilho dianteiro; sela sobre a sapata traseira |
| `02B_Sapata_X_Passiva_PETG.scad` | 1 sapata flutuante | desliza no trilho traseiro, sob a sela |
| `03_Trilho_Y.scad` | 1 viga Y com guia e rack | atravessa os dois carrinhos X; guia e rack para cima |
| `04_Carrinho_Y.scad` | 1 carrinho Y | desliza sobre a viga; sustenta motores Y/Z e módulo Z |
| `05_Modulo_Z_Caneta.scad` | êmbolo, colar, haste com mandril e buchas | dentro da guia Z do carrinho Y |
| `06_Pinhoes.scad` | 3 pinhões iguais | um em cada eixo de motor: X, Y e Z |
| `07_Batentes.scad` | 4 batentes X + 2 batentes Y | nas extremidades das três guias, após inserir os carrinhos |
| `08_Clips_Fixacao_Papel.scad` | 4 clips | nos cantos da área do papel |

Identifique os três pinhões como X, Y e Z depois do teste. Mesmo sendo iguais,
isso ajuda a relacionar um eventual defeito ao eixo correto.

### 2.2 Componentes não impressos

- 3 motores 28BYJ-48 compatíveis com os parâmetros atuais;
- 3 drivers apropriados para os motores;
- 1 mola de compressão compatível com os parâmetros atuais do Z;
- 1 base plana e rígida, normalmente MDF;
- 1 caneta para calibração e o pincel que será usado no final;
- cabos, fonte correta, controlador e itens de organização elétrica;
- fita dupla-face ou fixadores para os clips de papel.

Não compre a mola apenas pelo diâmetro. Confirme também comprimento livre,
curso útil e rigidez. Uma mola dimensionalmente correta pode exercer força
excessiva sobre o papel.

## 3. Parafusos e porcas

Esta é a lista inicial para a geometria atual. Os diâmetros e quantidades são
definidos pelas interfaces; o comprimento do M4 da base depende da espessura da
base e deve ser confirmado antes da compra definitiva.

| Quantidade | Fixador inicial | Aplicação | Aperto correto |
|---:|---|---|---|
| 8 | M4, comprimento conforme a base | quatro pontos de cada trilho X | firme, sem deformar o piso do trilho |
| 6 | M3x8 + 6 porcas M3 | dois parafusos em cada motor | alternado, apenas até a flange apoiar |
| 2 | M3x10 | uma extremidade da viga Y em cada carrinho X | rosca no furo piloto da chaveta; sem espanar o plástico |
| 1 | M3x8 | retenção da sela/sapata passiva | encostar no ressalto sem bloquear a flutuação |
| 1 | M3x12 + 1 porca M3 | colar da haste Z | suficiente para o colar não escorregar |
| 1 | M3x14 + 1 porca M3 | mandril da caneta ou pincel | suficiente para impedir giro, sem esmagar o cabo |

Total estrutural: **8 M4 + 11 M3 = 19 parafusos** e **8 porcas M3**.

Também é prudente separar arruelas M4 para a base e arruelas M3 para as flanges
dos motores. Os quatro clips aceitam fixação opcional; se forem parafusados,
adicione quatro fixadores compatíveis com a sua base. Eles não entram no total
estrutural porque podem ser presos com fita.

### Como confirmar o comprimento sem depender deste guia

1. Atravesse as peças sem apertar.
2. Some a espessura atravessada, arruela e porca.
3. Procure deixar alguns filetes completos além da porca, sem a ponta atingir
   rack, guia, motor ou mesa.
4. Nas roscas feitas diretamente no plástico, o parafuso deve alcançar o piloto
   sem atravessar a parede oposta.

## 4. Ordem dos testes

Não imprima trilhos e viga antes de aprovar os cupons físicos. Uma etapa só
avança quando o critério de aprovação estiver atendido.

### T0 — inspeção digital e geração dos STLs

Execute, com o OpenSCAD CLI instalado:

```bash
python3 validate_geometry.py
```

O resultado global deve ser `TODOS PASSARAM`. Erros de variável indefinida,
quantidade de componentes ou `min Z` devem ser resolvidos antes do fatiamento.

Para gerar as peças e os cupons físicos listados no script:

```bash
./build_stl.sh
```

### T1 — folga das guias: `99_Teste_Tolerancias.scad`

O cupom gera pares macho/fêmea em ordem crescente de folga.

1. Marque cada par ainda na mesa da impressora para não misturá-los.
2. Remova apenas rebarbas soltas.
3. Introduza cada macho na fêmea correspondente sem inclinar.
4. Teste o curso inteiro com os dedos, sem óleo.
5. Escolha a menor folga que percorra todo o curso sem ponto duro.

**Passou:** desliza sob pressão leve dos dedos, não cai sozinho e não balança
visivelmente. **Falhou apertado:** exige pancada, alicate ou força crescente.
**Falhou folgado:** desliza, mas apresenta inclinação ou batida lateral.

Registre o índice e o valor do par escolhido. Esse resultado calibra a família
de guias; ele não autoriza lixar todas as peças longas depois.

### T2 — perfil de engrenamento: `91_Teste_Engrenamento_FDM.scad`

1. Teste o furo D do pinhão num eixo de motor sem usar martelo.
2. Apoie o pinhão contra o rack curto mantendo os eixos paralelos.
3. Role o pinhão por vários dentes com leve pressão radial.
4. Repita depois de girar o pinhão meia volta no eixo.

**Passou:** rotação contínua, sem salto de dente e sem travamento periódico.
Uma pequena folga é preferível a pré-carga permanente. Se o ponto duro acompanha
o pinhão, investigue excentricidade ou furo D; se fica numa posição do rack,
investigue impressão do rack.

### T3 — espaço do pinhão: `99_Teste_Folga_Pinhao_FDM.scad`

O cupom contém um pinhão, um anel radial e um garfo axial.

1. Coloque o pinhão dentro do anel e gire-o em uma volta completa.
2. Passe o pinhão entre as paredes do garfo sem inclinar.
3. Procure marcas de raspagem nos dentes e nas faces.

**Passou:** gira no anel e atravessa o garfo sem ser forçado, mantendo folga
pequena. Esse teste valida o bolso livre ao redor do pinhão; não mede a folga
entre dentes do rack.

### T4 — mandril e buchas: `99B_Teste_Portaferramenta_FDM.scad`

1. Meça e teste a caneta e o pincel reais.
2. Use a menor bucha que aceite o cabo sem força.
3. Alinhe a fenda da bucha com a fenda do mandril.
4. Insira o cabo numa região aproximadamente cilíndrica, acima da virola.
5. Coloque a porca no alojamento e aperte o M3 gradualmente.
6. Faça um teste de giro e de tração com a mão.

**Passou:** a ferramenta não gira nem desce com força manual moderada, e o
mandril reabre quando o parafuso é solto. Não aperte sobre cerdas, virola fina
ou trecho cônico. Se a menor bucha ainda ficar folgada, relate o diâmetro real
do cabo para gerar outra bucha; não compense esmagando o mandril.

### T5 — testes paramétricos `92` e `93`

- `92_Teste_Estrutural.scad` verifica limites estruturais, espaço do papel,
  fabricação e curso da sapata.
- `93_Teste_Plano_Caneta.scad` verifica contato, elevação, força da mola e
  comprimento guiado do Z.

Ao renderizar, o resultado correto é somente o cubo marcador. Uma mensagem de
`assert` indica que algum parâmetro deixou a faixa segura.

### T6 — testes digitais de movimento e colisão `94`, `95`, `97` e `98`

- `94`: engrenamento amostrado durante um passo completo em X, Y e Z;
- `95`: interfaces entre trilhos, carrinhos, viga, pinhões e êmbolo;
- `97`: corpos, flanges, ressaltos e eixos dos três motores;
- `98`: verificação local rápida dos bolsos dos pinhões, guia Z e sapata.

Renderize com F6. O resultado correto é somente o cubo marcador distante.
Qualquer outra geometria exportada representa uma interseção real e deve ser
investigada; não prossiga porque o preview F5 “parece bom”.

### T7 — inspeção visual do curso: `96_Validacao_Curso.scad`

Renderize todas as posições definidas por `VALIDATION_POSITION`. Observe em
cada uma:

- se nenhum motor invade trilho, viga, outro motor ou ferramenta;
- se o pinhão permanece dentro do bolso e alinhado ao rack;
- se o êmbolo conserva apoio dentro da guia Z;
- se o porta-ferramenta não alcança a mesa;
- se cabos poderão acompanhar o movimento sem puxar os carrinhos.

Este teste mostra a montagem completa; nele não se aplica a regra do “somente
um cubo”.

## 5. Preparação das peças finais

1. Confirme que os STLs foram gerados depois da última alteração dos parâmetros.
2. Separe PLA e PETG conforme a tabela de peças.
3. Verifique empenamento dos dois trilhos e da viga sobre uma superfície plana.
4. Limpe canais, furos e entradas de guia sem aumentar suas dimensões.
5. Passe cada carrinho manualmente pela guia correspondente antes da montagem.
6. Teste cada pinhão no respectivo motor e identifique X, Y e Z.

Se uma peça longa prender somente numa extremidade, investigue empenamento ou
pé de elefante antes de aumentar globalmente a folga.

## 6. Montagem mecânica

### Etapa A — trilhos X na base

1. Posicione o trilho motriz na frente, com rack para cima e voltado para o lado
   externo da máquina.
2. Alinhe-o com uma referência reta e aperte seus quatro M4 gradualmente.
3. Posicione o trilho passivo atrás, paralelo ao primeiro.
4. Instale os quatro M4 traseiros apenas encostados; o ajuste final vem depois.
5. Não instale os batentes ainda.

### Etapa B — carrinhos X e apoio flutuante

1. Introduza o carrinho X motriz no trilho dianteiro pela extremidade.
2. Introduza a sapata PETG no trilho traseiro, com o ressalto voltado para cima.
3. Apoie a sela rígida sobre a sapata, encaixando o ressalto no bolso alongado.
4. Coloque o M3x8 pelo rasgo da sela e rosqueie no piloto da sapata.
5. Aperte até encostar no ressalto, nunca até prensar a sela.

**Controle:** a sela deve continuar se deslocando transversalmente dentro do
curso parametrizado, sem folga vertical perceptível.

### Etapa C — viga Y e esquadro do pórtico

1. Com os dois carrinhos na mesma posição longitudinal, assente os encaixes
   inferiores da viga nas chavetas dianteira e traseira.
2. Deixe a guia e o rack da viga voltados para cima.
3. Insira um M3x10 por cada face de extremidade e rosqueie nas chavetas.
4. Aperte alternadamente até a viga assentar, sem esmagar o plástico.
5. Desloque o pórtico manualmente por todo o X várias vezes.
6. Mantendo o movimento livre, aperte aos poucos os M4 do trilho traseiro em
   posições diferentes do curso.

**Controle:** o esforço deve permanecer parecido do início ao fim. Se endurece
nas pontas, solte o trilho passivo e refaça o paralelismo; não use o motor para
vencer desalinhamento.

### Etapa D — carrinho Y

1. Introduza o carrinho Y pela extremidade da viga antes dos batentes.
2. A guia fêmea fica sobre o rabo de andorinha da viga.
3. O bolso do pinhão Y deve coincidir com o rack da viga.
4. A face do motor Z fica voltada para a extremidade dianteira da viga; o motor
   Y fica na lateral externa do carrinho.
5. Percorra manualmente todo o Y e verifique esforço uniforme.

### Etapa E — êmbolo, mola e porta-ferramenta Z

1. Introduza o êmbolo na guia vertical com a cremalheira alinhada ao corredor
   externo e ao bolso do pinhão Z.
2. Insira a haste do porta-ferramenta por baixo, através do furo central.
3. Posicione a mola ao redor da haste, dentro da gaiola aberta do êmbolo.
4. Coloque o colar abaixo da mola e aperte seu M3 apenas o suficiente para que
   não escorregue. A mola deve ficar apoiada entre o colar e a tampa superior.
5. Acione o conjunto com a mão: ele deve comprimir e retornar sem raspar.
6. Instale a bucha aprovada e a ferramenta somente depois desse teste.

Se o colar não entrar lateralmente pela fenda sem risco de quebrar, não force:
desmonte o subconjunto, monte colar e mola na haste e repita a inserção. O colar
é recomendado em PETG justamente para tolerar essa abertura controlada.

### Etapa F — motores e pinhões

Repita para X, Y e Z:

1. Confira se o eixo D e o ressalto entram livremente no corredor coaxial.
2. Posicione o pinhão identificado no bolso e alinhe o lado plano ao eixo D.
3. Apoie a flange do motor na face externa da peça impressa.
4. Instale os dois M3x8 com porcas, deixando-os inicialmente frouxos.
5. Assente o pinhão no eixo sem martelo e sem usar o parafuso como prensa.
6. Gire o eixo manualmente e confirme que o pinhão não toca o bolso.
7. Aperte os dois parafusos alternadamente e repita a rotação.

**Controle:** o pinhão deve permanecer engrenado, mas o eixo precisa girar sem
pré-carga lateral. Se o motor solto gira e o apertado trava, revise assentamento
da flange, rebarba e alinhamento; não aumente corrente para mascarar o defeito.

### Etapa G — batentes, clips e ferramenta

1. Depois de todos os carrinhos estarem nas guias, pressione dois batentes em
   cada trilho X e um em cada extremidade da guia Y.
2. Instale os clips sem invadir o curso útil da ferramenta.
3. Coloque a bucha correspondente no mandril, alinhando as fendas.
4. Prenda caneta ou pincel pelo cabo redondo, nunca pelas cerdas ou virola.
5. Com a máquina desligada, ajuste o colar para produzir apenas a pré-carga
   definida nos parâmetros quando a ferramenta toca o papel.

## 7. Testes da máquina montada

Faça tudo primeiro sem energia:

1. mova X por todo o curso;
2. mova Y por todo o curso em três posições diferentes de X;
3. mova Z para baixo e solte; ele deve retornar;
4. gire cada motor lentamente pelo eixo e procure pontos duros;
5. confirme que nenhum cabo pode entrar em rack ou pinhão.

Depois energize um eixo por vez, em baixa velocidade e aceleração:

1. execute pequenos deslocamentos nos dois sentidos;
2. confirme sentido e limite antes de testar curso completo;
3. escute mudança de ruído e observe perda de passos;
4. repita com a ferramenta levantada e depois tocando levemente o papel;
5. pare imediatamente se houver travamento, salto de dentes ou aquecimento
   anormal.

Não alimente um motor nominal de 5 V diretamente com 12 V.

## 8. Primeiro desenho e primeiro teste com pincel

### Caneta

1. Prenda uma folha de rascunho.
2. Faça linhas horizontais e verticais curtas.
3. Faça um quadrado e duas diagonais.
4. Faça um círculo em baixa velocidade.
5. Observe falha de fechamento, ondulação, espessura irregular e marcas nas
   mudanças de direção.

### Pincel

1. Use tinta pouco carregada e uma folha protegendo a base.
2. Comece com força Z menor do que a usada na caneta.
3. Faça linhas retas em diferentes velocidades.
4. Verifique se o cabo gira no mandril e se as cerdas dobram sempre para o mesmo
   lado.
5. Só depois teste curvas e preenchimentos.

Pincel introduz arrasto variável, tinta e flexibilidade das cerdas. Um resultado
ruim com pincel não significa automaticamente defeito mecânico: compare sempre
com o teste de caneta feito na mesma montagem.

## 9. O que registrar e enviar para uma recalibração

Envie os resultados sem lixar os cupons, incluindo:

- foto dos cinco pares de tolerância ainda identificados;
- valor do menor par que deslizou livremente;
- vídeo curto do pinhão rolando no rack;
- foto do pinhão dentro do anel e entre as paredes do garfo;
- diâmetro real da caneta e do cabo do pincel no ponto de aperto;
- foto do `99B` segurando cada ferramenta e descrição do aperto necessário;
- vídeo do pórtico sendo movido à mão do início ao fim;
- eixo que apresentou ruído, folga, raspagem ou perda de passo;
- material, camada, paredes e qualquer compensação usada no fatiador.

Com esses dados, as alterações podem ser feitas nos parâmetros corretos sem
redesenhar a estrutura nem repetir impressões grandes desnecessariamente.

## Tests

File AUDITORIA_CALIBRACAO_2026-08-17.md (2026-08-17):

# Auditoria de calibração — CNC Plotter 28BYJ-48

Data: 2026-08-17  
Impressora de referência: Bambu Lab A1, PLA, bico 0.4 mm

## Parâmetros aprovados

- `slide_clearance_xy = 0.22` mm — Teste 99, par #3.
- `slide_clearance_z = 0.15` mm.
- `passive_float = 0.60` mm.
- `pressfit_clearance = 0.15` mm.
- `shaft_clearance = 0.18` mm — teste físico do eixo Double-D, pinhão #1.
- 28BYJ-48: corpo Ø28.0 mm, montagem 35.0 mm, eixo Ø5.0 mm, seção Double-D 3.0 mm, faces 6.0 mm, eixo livre 8.5 mm, furos de flange r=2.1 mm, boss r=4.5 mm.

## Resultado da revisão arquivo por arquivo

| Arquivo | Resultado |
|---|---|
| `00_Parametros.scad` | **OK.** Parâmetros calibrados presentes; `d_shaft_hole()` e `d_shaft_solid()` usam dois cortes simétricos; `pinion_gear()` repassa `clearance`. |
| `01_Base_Trilho_X.scad` | **OK.** Usa `dovetail_male_x()` global; sem constantes antigas do motor. |
| `01B_Trilho_X_Passivo.scad` | **OK.** Apenas reutiliza o trilho X paramétrico. |
| `02_Carrinho_X.scad` | **OK.** Não existe bolso para o corpo Ø28: o corpo do motor fica fora da peça por projeto. O corredor usa `motor_boss_r`, `motor_shaft_r`, `motor_shaft_length` e os furos usam `motor_flange_hole_r`. |
| `02B_Sapata_X_Passiva_PETG.scad` | **OK.** Reutiliza a sapata paramétrica. |
| `03_Trilho_Y.scad` | **OK.** Sem parâmetros de motor duplicados; geometria principal já modelada sem suporte. |
| `04_Carrinho_Y.scad` | **OK.** Motores Y/Z ficam com o corpo fora da peça; corredores usam boss/eixo globais e os furos usam `motor_flange_hole_r`. |
| `05_Modulo_Z_Caneta.scad` | **OK.** Orelhas M3 já possuem base autoportante a 45° e o teto interno é cônico. |
| `06_Pinhoes.scad` | **OK.** Todos os pinhões chamam `pinion_gear()`, portanto usam `shaft_clearance=0.18` e Double-D global. |
| `07_Batentes.scad` | **CORRIGIDO.** Havia `clearance=0.10` hardcoded. Como o encaixe é de pressão, foi substituído por `pressfit_clearance=0.15`, não pela folga deslizante de 0.22. |
| `08_Clips_Fixacao_Papel.scad` | **CORRIGIDO.** Entrada inclinada passou de 30° para chanfro autoportante de 45°. |
| `90_Componentes_Referencia.scad` | **OK.** Modelo visual real usa `d_shaft_solid()` Double-D. O envelope de colisão do eixo permanece cilíndrico de propósito por ser conservador. |
| `91_Teste_Engrenamento_FDM.scad` | **OK.** Pinhão herda Double-D e folga global. |
| `92_Teste_Estrutural.scad` | **OK.** Guardas estruturais não duplicam calibrações. |
| `93_Teste_Plano_Caneta.scad` | **OK.** Sem dependências conflitantes do motor/folgas XY. |
| `94_Teste_Engrenamento_Dinamico.scad` | **OK.** Usa transmissão e pinhões paramétricos. |
| `95_Teste_Montagem_Completa.scad` | **OK.** Usa apenas módulos paramétricos compartilhados. |
| `96_Validacao_Curso.scad` | **OK.** Montagem completa reutilizada sem constantes antigas. |
| `97_Diagnostico_Motores.scad` | **OK.** Envelopes dos motores vêm de `90_Componentes_Referencia.scad`; sem dimensões antigas hardcoded. |
| `98_Teste_Interferencias.scad` | **OK.** Pinhões/carrinhos paramétricos. |
| `99_Teste_Tolerancias.scad` | **CORRIGIDO.** O arquivo não refletia a série realmente impressa. Agora registra `[0.14, 0.18, 0.22, 0.26, 0.30]` e identifica 0.22 mm como vencedor. |
| `99_Teste_Eixo_D.scad` | **CORRIGIDO.** A descrição antiga chamava 0.22 mm de nominal; agora registra 0.18 mm como resultado aprovado e identifica explicitamente o eixo Double-D. |
| `99_Teste_Folga_Pinhao_FDM.scad` | **OK.** Usa o pinhão global e parâmetros de bolso. |
| `99B_Teste_Portaferramenta_FDM.scad` | **OK.** Reutiliza o módulo Z já autoportante. |
| `CNC_Plotter_Full_Assembly.scad` | **OK.** Motores e pinhões vêm dos módulos paramétricos revisados. |
| `CNC_Plotter_Animated_Simulation.scad` | **OK.** Apenas anima a montagem paramétrica. |
| `placa_testes_completa.scad` | **OK.** Pinhões usam `pinion_gear()` global e porta-ferramenta usa o módulo Z revisado. |
| `scratch_frames_99/frame_000.scad` a `frame_023.scad` | **OK.** Arquivos gerados de visualização adicionados no commit `4b927a7`; todos usam `c=0.22`, módulos dovetail globais e não duplicam dimensões de motor. |
| `99C_Validacao_Parametros_Calibrados.scad` | **NOVO.** Assertions impedem regressão das calibrações e cotas do 28BYJ-48. |

## Observações de geometria FDM

- Não foi necessário alterar `01_Base_Trilho_X.scad`, `03_Trilho_Y.scad`, `04_Carrinho_Y.scad` ou `05_Modulo_Z_Caneta.scad`: as regiões verificadas estão apoiadas, ligadas ao corpo, ou já usam geometrias autoportantes.
- A ponte de fixação do motor X em `02_Carrinho_X.scad` está ligada ao corpo ao longo da face de montagem; não é um cantilever suspenso isolado.
- O único ponto adicional claramente abaixo do critério desejado de 45° foi a entrada dos clips, corrigida em `08_Clips_Fixacao_Papel.scad`.

## Build e regressão

- `build_stl.sh` agora inclui `99_Teste_Eixo_D.scad` e `placa_testes_completa.scad`, que estavam fora do lote automático.
- A workflow `.github/workflows/openscad-validation.yml` compila os STLs imprimíveis, executa a guarda de parâmetros e roda `validate_geometry.py`.
- Os STLs gerados continuam fora do versionamento (`/*.stl` no `.gitignore`) e são publicados como artefato temporário da CI.

## Arquivos de referência

- `28BYJ-48-dimensions.webp` está presente no branch `master`.
- `StepMotorModel.stl` **não está presente na árvore atual do branch `master`** no momento desta auditoria. Por isso, a verificação dimensional foi baseada nas cotas fornecidas e no datasheet já versionado.

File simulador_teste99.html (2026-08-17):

# Teste 99 — Dovetail Simulação 3D

Simulador interativo do cupom de tolerâncias para os eixos lineares X e Y (Perfil Rabo de Andorinha).

Corte Transversal 2D 0.22 mm

Macho / Guia Linear (Trilho)

Fêmea / Canal de Deslizamento

Parâmetros de Tolerância Par #3

Folga por lado (c) 0.22 mm

Folga total no topo 0.44 mm

Largura da base macho 9.50 mm

Largura do topo macho 13.00 mm

Altura útil da guia (h) 4.50 mm

Comprimento do cupom 20.00 mm

⭐ Padrão Recomendado (0.22 mm):
Equilíbrio ideal entre movimento suave por gravidade e rigidez lateral sem folga perceptível (*wobble*).

Critério de Aprovação Física:
1. O macho deve deslizar pelo próprio peso ou com leve toque.
2. Não deve haver jogo angular perpendicular ao eixo.
3. Sem necessidade de lixa ou força excessiva.

0.18 mm 0.20 mm 0.22 mm (Nominal) 0.25 mm 0.28 mm

Mostrar Todos os 5 Pares Corte 2D Wireframe

▶ Animar Deslizamento

Posição Linear (X): 0.0 mm

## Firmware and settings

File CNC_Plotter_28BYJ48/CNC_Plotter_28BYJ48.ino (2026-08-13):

/*
  CNC Plotter 28BYJ-48 + ULN2003 (Arduino Uno) - Version 7.0 (Calibrated X & Y)
  ----------------------------------------------------------------------------
  Firmware com calibração precisa dos eixos X e Y:
  - STEPS_PER_MM_X = 71.4286 (Medido: 20mm sol. = 28mm real)
  - STEPS_PER_MM_Y = 90.9091 (Medido: 20mm sol. = 22mm real)
  - STEPS_PER_MM_Z = 160.0000 (Precisão fina no Z)
*/

#include <Arduino.h>

int pinX[4] = {2, 3, 4, 5};     // Eixo X
int pinY[4] = {A0, A1, A2, A3}; // Eixo Y
int pinZ[4] = {6, 7, 8, 9};     // Eixo Z

bool INVERT_X = false;
bool INVERT_Y = true;  // Eixo Y Invertido
bool INVERT_Z = true;  // Eixo Z Invertido

// Calibração Precisa de Passos por Millímetro (Regra de 3)
float STEPS_PER_MM_X = 71.4286; // Calibrado: 100 * (20 / 28)
float STEPS_PER_MM_Y = 90.9091; // Calibrado: 100 * (20 / 22)
float STEPS_PER_MM_Z = 160.0;

long stepDelayUS_XY = 1500;
long stepDelayUS_Z  = 2000;

float currentX = 0.0;
float currentY = 0.0;
float currentZ = 0.0;
bool absoluteMode = true;

const byte stepSequence[8] = {
  B00001000,
  B00001100,
  B00000100,
  B00000110,
  B00000010,
  B00000011,
  B00000001,
  B00001001
};

int stepIndexX = 0;
int stepIndexY = 0;
int stepIndexZ = 0;

void setMotorOutput(const int pins[4], byte pattern) {
  digitalWrite(pins[0], (pattern & B00001000) ? HIGH : LOW);
  digitalWrite(pins[1], (pattern & B00000100) ? HIGH : LOW);
  digitalWrite(pins[2], (pattern & B00000010) ? HIGH : LOW);
  digitalWrite(pins[3], (pattern & B00000001) ? HIGH : LOW);
}

void disableMotor(const int pins[4]) {
  for (int i = 0; i < 4; i++) {
    digitalWrite(pins[i], LOW);
  }
}

void stepMotor(int axis, int dir) {
  if (axis == 0) {
    int effectiveDir = INVERT_X ? -dir : dir;
    stepIndexX = (stepIndexX + effectiveDir + 8) % 8;
    setMotorOutput(pinX, stepSequence[stepIndexX]);
  } else if (axis == 1) {
    int effectiveDir = INVERT_Y ? -dir : dir;
    stepIndexY = (stepIndexY + effectiveDir + 8) % 8;
    setMotorOutput(pinY, stepSequence[stepIndexY]);
  } else if (axis == 2) {
    int effectiveDir = INVERT_Z ? -dir : dir;
    stepIndexZ = (stepIndexZ + effectiveDir + 8) % 8;
    setMotorOutput(pinZ, stepSequence[stepIndexZ]);
  }
}

void moveTo(float targetX, float targetY, float targetZ) {
  long targetStepsX = lround(targetX * STEPS_PER_MM_X);
  long targetStepsY = lround(targetY * STEPS_PER_MM_Y);
  long targetStepsZ = lround(targetZ * STEPS_PER_MM_Z);

  long startStepsX = lround(currentX * STEPS_PER_MM_X);
  long startStepsY = lround(currentY * STEPS_PER_MM_Y);
  long startStepsZ = lround(currentZ * STEPS_PER_MM_Z);

  long deltaX = abs(targetStepsX - startStepsX);
  long deltaY = abs(targetStepsY - startStepsY);
  long deltaZ = abs(targetStepsZ - startStepsZ);

  int dirX = (targetStepsX >= startStepsX) ? 1 : -1;
  int dirY = (targetStepsY >= startStepsY) ? 1 : -1;
  int dirZ = (targetStepsZ >= startStepsZ) ? 1 : -1;

  long maxSteps = max(deltaX, max(deltaY, deltaZ));
  if (maxSteps == 0) return;

  long errX = maxSteps / 2;
  long errY = maxSteps / 2;
  long errZ = maxSteps / 2;

  long currentDelay = (deltaZ > 0 && deltaX == 0 && deltaY == 0) ? stepDelayUS_Z : stepDelayUS_XY;

  for (long i = 0; i < maxSteps; i++) {
    errX -= deltaX;
    if (errX < 0) {
      errX += maxSteps;
      stepMotor(0, dirX);
    }

    errY -= deltaY;
    if (errY < 0) {
      errY += maxSteps;
      stepMotor(1, dirY);
    }

    errZ -= deltaZ;
    if (errZ < 0) {
      errZ += maxSteps;
      stepMotor(2, dirZ);
    }

    delayMicroseconds(currentDelay);
  }

  currentX = targetX;
  currentY = targetY;
  currentZ = targetZ;

  disableMotor(pinX);
  disableMotor(pinY);
  disableMotor(pinZ);
}

float parseValue(String line, char code, float defaultValue) {
  int index = line.indexOf(code);
  if (index == -1) return defaultValue;
  int end = index + 1;
  while (end < line.length() && (isDigit(line[end]) || line[end] == '.' || line[end] == '-')) {
    end++;
  }
  return line.substring(index + 1, end).toFloat();
}

void processGCode(String line) {
  line.trim();
  if (line.length() == 0 || line.startsWith("(")) return;

  if (line == "?") {
    Serial.print("<Idle|MPos:");
    Serial.print(currentX, 3); Serial.print(",");
    Serial.print(currentY, 3); Serial.print(",");
    Serial.print(currentZ, 3);
    Serial.println("|F:0>");
    Serial.println("ok");
    return;
  }

  if (line.startsWith("G0") || line.startsWith("G00") || line.startsWith("G1") || line.startsWith("G01")) {
    float nextX = parseValue(line, 'X', absoluteMode ? currentX : 0.0);
    float nextY = parseValue(line, 'Y', absoluteMode ? currentY : 0.0);
    float nextZ = parseValue(line, 'Z', absoluteMode ? currentZ : 0.0);

    if (!absoluteMode) {
      nextX += currentX;
      nextY += currentY;
      nextZ += currentZ;
    }

    moveTo(nextX, nextY, nextZ);
    Serial.println("ok");
  } else if (line.startsWith("G90")) {
    absoluteMode = true;
    Serial.println("ok");
  } else if (line.startsWith("G91")) {
    absoluteMode = false;
    Serial.println("ok");
  } else if (line.startsWith("G28")) {
    moveTo(0, 0, 0);
    Serial.println("ok");
  } else if (line.startsWith("G21") || line.startsWith("M3") || line.startsWith("M5") || line.startsWith("M2")) {
    Serial.println("ok");
  } else {
    Serial.println("ok");
  }
}

void setup() {
  Serial.begin(115200);

  for (int i = 0; i < 4; i++) {
    pinMode(pinX[i], OUTPUT);
    pinMode(pinY[i], OUTPUT);
    pinMode(pinZ[i], OUTPUT);
  }

  disableMotor(pinX);
  disableMotor(pinY);
  disableMotor(pinZ);

  Serial.println("CNC Plotter v7.0 - X e Y Calibrados Exatamente");
}

String inputBuffer = "";

void loop() {
  while (Serial.available() > 0) {
    char c = Serial.read();
    if (c == '\n' || c == '\r') {
      if (inputBuffer.length() > 0) {
        processGCode(inputBuffer);
        inputBuffer = "";
      }
    } else {
      inputBuffer += c;
    }
  }
}

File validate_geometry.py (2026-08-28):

#!/usr/bin/env python3
"""
=============================================================================
validate_geometry.py - Validação Geométrica Completa da CNC Plotter
=============================================================================
Compila cada SCAD -> STL via OpenSCAD CLI, depois analisa:
  1. Warnings de código do OpenSCAD (unknown variable, undef, undefined operation)
  2. Componentes conectados (via adjacência de vértices dos triângulos)
  3. Bounding boxes (min/max em X, Y, Z)
  4. min Z das peças (deve ser >= 0 para orientação FDM)
=============================================================================
"""

import subprocess, os, struct, sys, re
from pathlib import Path

CNC_DIR = Path(__file__).resolve().parent

# Peças a compilar e suas expectativas de componentes
# expected = -1 indica arquivo de montagem/referência (não-imprimível isoladamente)
PIECES = [
    ('01_Base_Trilho_X.scad',            '01_Base_Trilho_X.stl',            1),
    ('01B_Trilho_X_Passivo.scad',        '01B_Trilho_X_Passivo.stl',        1),
    ('02_Carrinho_X.scad',               '02_Carrinho_X.stl',               2),
    ('02B_Sapata_X_Passiva_PETG.scad',   '02B_Sapata_X_Passiva_PETG.stl',   1),
    # Uma peca fisica; os seis vazios fechados aparecem como cascas internas
    # independentes no STL, portanto o contador topologico retorna 7.
    ('03_Trilho_Y.scad',                 '03_Trilho_Y.stl',                 7),
    ('04_Carrinho_Y.scad',               '04_Carrinho_Y.stl',               1),
    # Embolo, colar, mandril/haste e tres buchas redutoras.
    ('05_Modulo_Z_Caneta.scad',          '05_Modulo_Z_Caneta.stl',          6),
    ('06_Pinhoes.scad',                  '06_Pinhoes.stl',                  3),
    ('07_Batentes.scad',                 '07_Batentes.stl',                 6),
    ('08_Clips_Fixacao_Papel.scad',      '08_Clips_Fixacao_Papel.stl',      4),
    ('91_Teste_Engrenamento_FDM.scad',   '91_Teste_Engrenamento_FDM.stl',   2),
    ('92_Teste_Estrutural.scad',         '92_Teste_Estrutural.stl',         1),
    ('93_Teste_Plano_Caneta.scad',       '93_Teste_Plano_Caneta.stl',       1),
    ('94_Teste_Engrenamento_Dinamico.scad','94_Teste_Engrenamento_Dinamico.stl',1),
    ('95_Teste_Montagem_Completa.scad',  '95_Teste_Montagem_Completa.stl',  1),
    ('97_Diagnostico_Motores.scad',      '97_Diagnostico_Motores.stl',      1),
    ('98_Teste_Interferencias.scad',     '98_Teste_Interferencias.stl',     1),
    ('99_Teste_Tolerancias.scad',        '99_Teste_Tolerancias.stl',       10),
    ('99_Teste_Folga_Pinhao_FDM.scad',   '99_Teste_Folga_Pinhao_FDM.stl',   3),
    ('99B_Teste_Portaferramenta_FDM.scad','99B_Teste_Portaferramenta_FDM.stl',4),
    ('99D_Teste_Fixacao_Motor_28BYJ48.scad','99D_Teste_Fixacao_Motor_28BYJ48.stl',1),
    ('90_Componentes_Referencia.scad',   '90_Componentes_Referencia.stl',  -1),
    ('96_Validacao_Curso.scad',          '96_Validacao_Curso.stl',         -1),
    ('CNC_Plotter_Full_Assembly.scad',   'CNC_Plotter_Full_Assembly.stl',  -1),
]

# O teste 95 combina dezenas de intersection() vazias. OpenSCAD 2021 pode
# emitir aviso de 2-manifold durante a avaliacao, mesmo quando o STL final e
# somente o cubo marcador valido. Warnings de codigo continuam proibidos.
ALLOW_MANIFOLD_WARNING = {'95_Teste_Montagem_Completa.scad'}

def compile_scad(scad_file, stl_file):
    """Compila SCAD -> STL, retorna (sucesso, warnings_list, stderr)."""
    scad_path = CNC_DIR / scad_file
    stl_path  = CNC_DIR / stl_file
    
    cmd = ['openscad', '-o', str(stl_path), str(scad_path)]
    result = subprocess.run(cmd, capture_output=True, text=True, timeout=240)
    
    stderr = result.stderr
    warnings = []
    for line in stderr.split('\n'):
        ll = line.lower()
        if any(kw in ll for kw in ['warning', 'unknown variable', 'undef', 'undefined operation']):
            warnings.append(line.strip())
    
    success = os.path.exists(stl_path) and os.path.getsize(stl_path) > 84
    return success, warnings, stderr

def parse_stl(filepath):
    """Parse ASCII or Binary STL file into list of triangles."""
    with open(filepath, 'rb') as f:
        data = f.read()
    
    if data.strip().startswith(b'solid'):
        try:
            text = data.decode('utf-8', errors='ignore')
            vertices = re.findall(r'vertex\s+([-+]?\d*\.?\d+(?:[eE][-+]?\d+)?)\s+([-+]?\d*\.?\d+(?:[eE][-+]?\d+)?)\s+([-+]?\d*\.?\d+(?:[eE][-+]?\d+)?)', text)
            triangles = []
            for i in range(0, len(vertices) - 2, 3):
                v1 = (round(float(vertices[i][0]), 3), round(float(vertices[i][1]), 3), round(float(vertices[i][2]), 3))
                v2 = (round(float(vertices[i+1][0]), 3), round(float(vertices[i+1][1]), 3), round(float(vertices[i+1][2]), 3))
                v3 = (round(float(vertices[i+2][0]), 3), round(float(vertices[i+2][1]), 3), round(float(vertices[i+2][2]), 3))
                triangles.append((v1, v2, v3))
            return triangles
        except Exception:
            pass

    triangles = []
    if len(data) >= 84:
        num_tri = struct.unpack('<I', data[80:84])[0]
        offset = 84
        for _ in range(num_tri):
            if offset + 50 > len(data):
                break
            vals = struct.unpack('<12fH', data[offset:offset+50])
            v1 = (round(vals[3], 3), round(vals[4], 3), round(vals[5], 3))
            v2 = (round(vals[6], 3), round(vals[7], 3), round(vals[8], 3))
            v3 = (round(vals[9], 3), round(vals[10], 3), round(vals[11], 3))
            triangles.append((v1, v2, v3))
            offset += 50
    return triangles

def count_connected_components(filepath):
    """Count connected components using Union-Find on shared vertices."""
    triangles = parse_stl(filepath)
    if not triangles:
        return 0, None, None
    
    parent = {}
    
    def find(x):
        while parent[x] != x:
            parent[x] = parent[parent[x]]
            x = parent[x]
        return x
    
    def union(a, b):
        ra, rb = find(a), find(b)
        if ra != rb:
            parent[ra] = rb
    
    for v1, v2, v3 in triangles:
        for v in (v1, v2, v3):
            if v not in parent:
                parent[v] = v
        union(v1, v2)
        union(v2, v3)
    
    roots = set(find(v) for v in parent)
    num_components = len(roots)
    
    all_verts = list(parent.keys())
    xs = [v[0] for v in all_verts]
    ys = [v[1] for v in all_verts]
    zs = [v[2] for v in all_verts]
    
    bbox_min = (min(xs), min(ys), min(zs))
    bbox_max = (max(xs), max(ys), max(zs))
    
    return num_components, bbox_min, bbox_max
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

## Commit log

2026-08-13 Initial commit: CNC Plotter 28BYJ-48 OpenSCAD & KCL project calibrated for Bambu Lab A1
    [00_Parametros.scad, 01_Base_Trilho_X.scad, 01_Base_Trilho_X.stl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]
2026-08-13 Corrige geometria mecânica e módulo Z
    Consolida o OpenSCAD corrigido como fonte oficial, adiciona validacoes de interferencia e remove STLs antigos da raiz.
    [00_Parametros.scad, 01_Base_Trilho_X.scad, 01_Base_Trilho_X.stl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]
2026-08-13 Elimina colisões físicas na montagem da plotter
    Move motor/cremalheira X para a face frontal, redimensiona o carrinho Y para a furação real do 28BYJ-48 e adiciona testes CSG de colisão em todo o curso.
    [00_Parametros.scad, 01_Base_Trilho_X.scad, 02_Carrinho_X.scad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]
2026-08-13 Corrige sobreposições e peças flutuantes da montagem
    Abre canais para as cremalheiras X/Y, separa o acionamento Y do módulo Z, move a cremalheira Z para a face externa, adiciona retenção M3 e valida colisões no curso completo.
    [00_Parametros.scad, 01_Base_Trilho_X.scad, 02_Carrinho_X.scad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]
2026-08-13 Redesenha pórtico com duplo apoio X
    [00_Parametros.scad, 01B_Trilho_X_Passivo.scad, 01_Base_Trilho_X.scad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]
2026-08-13 Adiciona cupom físico de engrenamento
    [91_Teste_Engrenamento_FDM.scad]
2026-08-13 Corrige apoio e passagens dos motores
    [00_Parametros.scad, 02_Carrinho_X.scad, 04_Carrinho_Y.scad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]
2026-08-13 Corrige transparência visual dos pinhões
    [00_Parametros.scad, 06_Pinhoes.scad, CNC_Plotter_Full_Assembly.scad]
2026-08-13 Alinha motor Y e solidifica preview dos pinhões
    [00_Parametros.scad, 90_Componentes_Referencia.scad, 97_Diagnostico_Motores.scad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]
2026-08-14 Aumenta folga real dos bolsos de pinhão
    Amplia somente os bolsos dos pinhões X, Y e Z para tolerar impressão FDM sem alterar a distância de engrenamento. Adiciona cupom físico de folga radial e axial.
    [00_Parametros.scad, 02_Carrinho_X.scad, 04_Carrinho_Y.scad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]
2026-08-14 Adiciona porta-ferramenta universal para caneta e pincel
    Mantém a haste guiada de 10 mm e acrescenta mandril externo com buchas redutoras e cupom físico de teste.
    [00_Parametros.scad, 05_Modulo_Z_Caneta.scad, 99B_Teste_Portaferramenta_FDM.scad]
2026-08-14 Adiciona guia completo de testes e montagem
    Documenta cupons, fixadores, encaixes, montagem por subconjuntos e critérios para futuras recalibrações.
    [validate_geometry.py]
2026-08-14 Adiciona guia visual de testes e montagem
    Inclui infográfico vetorial com cupons, peças, fixadores, sequência de montagem e módulo Z.
2026-08-14 Atualiza roadmap para os testes físicos
    Organiza cupons, montagem, elétrica, calibração e validação final em fases com critérios de avanço.
2026-08-17 Calibra folgas com testes físicos (Bambu A1 PLA 0.4mm)
    Resultados dos testes físicos:
    - slide_clearance_xy = 0.22 mm (Teste 99, Par #3)
    - shaft_clearance = 0.18 mm (Teste Eixo D, Pinhão #1)
    Correções aplicadas ao motor 28BYJ-48:
    - Geometria do eixo corrigida de D simples para Double-D (duplo chanfro simétrico)
    - Cotas atualizadas com base no datasheet oficial Mouser/Kiatronics:
    motor_body_diameter 28.2 -> 28.0, motor_flange_hole_r 1.6 -> 2.1,
    motor_boss_r 4.6 -> 4.5, motor_shaft_length 9.0 -> 8.5
    - Adicionado chanfro guia de entrada (0.6mm) no furo do eixo (anti pé de elefante)
    - Adicionado chanfro 45° nas orelhas M3 do módulo Z (anti overhang)
    Novos arquivos:
    - 99_Teste_Eixo_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
    [00_Parametros.scad, 05_Modulo_Z_Caneta.scad, 99_Teste_Eixo_D.scad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]
2026-08-17 Audita calibração FDM e protege parâmetros do 28BYJ-48
    - corrige batentes para usar pressfit_clearance=0.15
    - atualiza Teste 99 para a série realmente impressa e 0.22 mm aprovado
    - registra 0.18 mm como folga aprovada do eixo Double-D
    - muda entrada dos clips para chanfro autoportante de 45 graus
    - inclui cupom Double-D e placa completa no build de STLs
    - adiciona guarda de regressão dos parâmetros calibrados
    - adiciona CI OpenSCAD com compilação, validação geométrica e artefatos STL
    - documenta auditoria arquivo por arquivo
    [07_Batentes.scad, 08_Clips_Fixacao_Papel.scad, 99C_Validacao_Parametros_Calibrados.scad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]
2026-08-17 Corrige pose isolada do modelo de referência na validação
    O módulo do 28BYJ-48 mantém a face de montagem em Z=0 e o corpo em Z negativo, como requerido pela montagem. Apenas a chamada top-level de 90_Componentes_Referencia.scad é deslocada para min Z=0, eliminando falso positivo do validador geométrico.
    [90_Componentes_Referencia.scad]
2026-08-28 refactor: centralize 28BYJ-48 mount interface
    [00_Parametros.scad]
2026-08-28 refactor: mount X motor from shaft datum
    [02_Carrinho_X.scad]
2026-08-28 refactor: mount Y and Z motors from shaft datum
    [04_Carrinho_Y.scad]
2026-08-28 fix: model real 28BYJ-48 flange offset
    [90_Componentes_Referencia.scad]
2026-08-28 fix: place motor fasteners from canonical flange pattern
    [CNC_Plotter_Full_Assembly.scad]
2026-08-28 test: add physical 28BYJ-48 mount coupon
    [99D_Teste_Fixacao_Motor_28BYJ48.scad]
2026-08-28 test: build motor mount coupon
2026-08-28 test: validate motor mount coupon
2026-08-28 docs: document calibrated motor mount interface
2026-08-31 chore: padroniza artefatos de impressao em 3mf
2026-08-31 chore: remove STL legado 1
    [1.stl]
2026-08-31 chore: remove STL legado 2
    [2.stl]
2026-08-31 chore: remove STL legado 3
    [3.stl]
2026-08-31 chore: remove STL legado 4
    [4.stl]
2026-08-31 chore: remove STL legado 5
    [5.stl]
2026-08-31 chore: remove STL legado 6
    [6.stl]
2026-08-31 chore: remove STL legado 7
    [7.stl]
2026-08-31 chore: remove STL legado 8
    [8.stl]
2026-08-31 chore: remove STL legado 9
    [9.stl]
2026-08-31 chore: remove STL legado A
    [A.stl]
2026-08-31 chore: remove STL legado Arduino N1
    [Arduino_mini_CNC_plotter-N1.stl]
2026-08-31 chore: remove STL legado pen holder
    [Arduino_mini_CNC_plotter_pen_holder-10mm.stl]
2026-08-31 chore: remove STL legado B
    [B.stl]
2026-08-31 chore: remove STL legado New Z Rail
    [New_Z_Rail.stl]
2026-08-31 chore: remove STL legado New Z Slide
    [New_Z_Slide.stl]
2026-08-31 print: adiciona 3MF Bambu do carrinho X
    [02_Carrinho_X.3mf]
2026-08-31 print: automate Bambu Lab 3MF package
2026-08-31 print: add Bambu Lab 3MF builder
2026-08-31 print: generate Bambu Lab 3MF package
    [01B_Trilho_X_Passivo.3mf, 01_Base_Trilho_X.3mf, 02B_Sapata_X_Passiva_PETG.3mf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]
2026-08-31 fix: regenerate Carrinho X 3MF from current CAD
2026-08-31 fix: lock final 28BYJ-48 motor mounts
    [00_MotorMount_Final.scad, 02_Carrinho_X.scad, 04_Carrinho_Y.scad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]
2026-08-31 fix: use two round M3 holes for final motor mounts
    [00_MotorMount_Final.scad]
2026-08-31 docs: align Carrinho X with round motor holes
    [02_Carrinho_X.scad]
2026-08-31 docs: align Carrinho YZ with round motor holes
    [04_Carrinho_Y.scad]
2026-08-31 test: lock 99D to two round motor holes
    [99D_Teste_Fixacao_Motor_28BYJ48.scad]
2026-08-31 print: add native Bambu Studio project 3MF builder
2026-08-31 print: generate Bambu Studio project 3MF package
    [01B_Trilho_X_Passivo.3mf, 01_Base_Trilho_X.3mf, 02B_Sapata_X_Passiva_PETG.3mf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]
2026-08-31 print: keep Bambu project package clean
